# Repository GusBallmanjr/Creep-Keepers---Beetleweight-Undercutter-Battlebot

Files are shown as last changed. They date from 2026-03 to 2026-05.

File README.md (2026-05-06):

# 3 lb Undercutter BattleBot
## Crimson Robotics (Washington State University)

**Creep Keepers** - Gus Ballman[^1], Carson Roskelley[^2], Jayden Claytor[^3], Natalie Massarenti[^4]

---

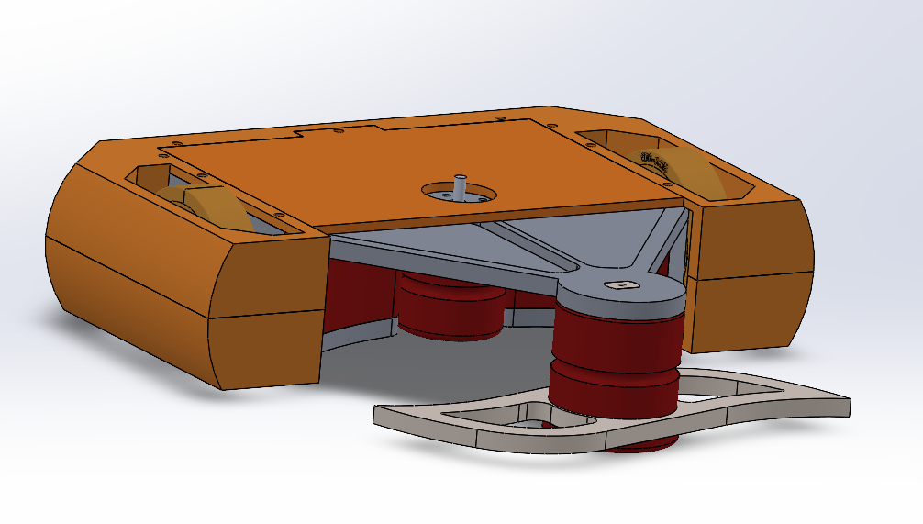
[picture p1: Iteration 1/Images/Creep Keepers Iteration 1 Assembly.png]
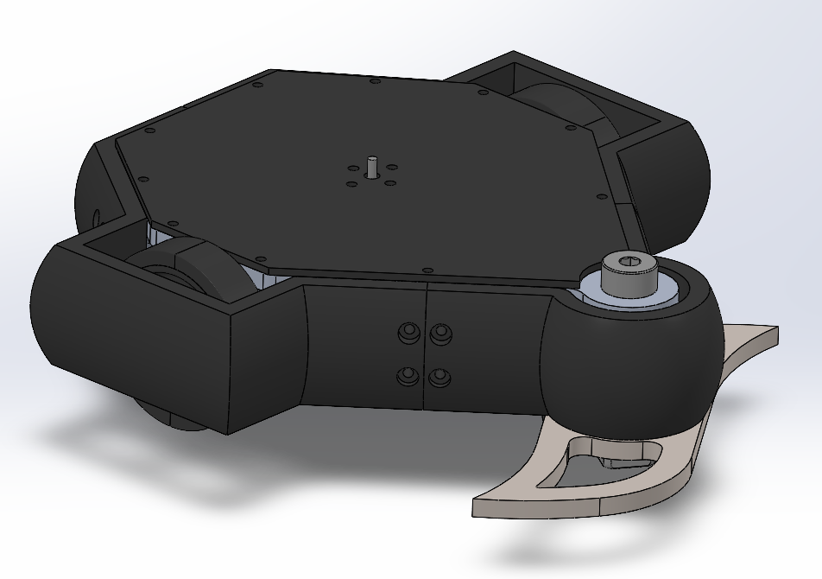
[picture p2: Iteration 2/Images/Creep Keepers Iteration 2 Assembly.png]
  <br>
&nbsp;&nbsp;&nbsp;&nbsp;&nbsp;&nbsp;&nbsp;&nbsp;&nbsp;&nbsp;&nbsp;&nbsp;&nbsp;&nbsp;&nbsp;&nbsp;&nbsp;&nbsp;&nbsp;&nbsp;&nbsp;&nbsp;&nbsp;&nbsp;&nbsp;&nbsp;&nbsp;&nbsp; *Iteration 1* &nbsp;&nbsp;&nbsp;&nbsp;&nbsp;&nbsp;&nbsp;&nbsp;&nbsp;&nbsp;&nbsp;&nbsp;&nbsp;&nbsp;&nbsp;&nbsp;&nbsp;&nbsp;&nbsp;&nbsp;&nbsp;&nbsp;&nbsp;&nbsp;&nbsp;&nbsp;&nbsp;&nbsp;&nbsp;&nbsp;&nbsp;&nbsp;&nbsp;&nbsp;&nbsp;&nbsp;&nbsp;&nbsp;&nbsp;&nbsp;&nbsp;&nbsp;&nbsp;&nbsp;&nbsp;&nbsp;&nbsp;&nbsp;&nbsp;&nbsp;&nbsp;&nbsp;&nbsp;&nbsp;&nbsp;&nbsp;&nbsp;&nbsp;&nbsp;&nbsp;&nbsp;&nbsp;&nbsp;&nbsp;&nbsp;&nbsp;&nbsp;&nbsp;&nbsp;&nbsp;&nbsp;&nbsp;&nbsp;&nbsp;&nbsp;&nbsp;&nbsp;&nbsp;&nbsp;&nbsp; *Iteration 2* &nbsp;&nbsp;&nbsp;&nbsp;

---

#### Iterations
+ [Prototype Files & Documentation](https://github.com/GusBallmanjr/Creep-Keepers---Beetleweight-Undercutter-Battlebot/blob/main/Prototype/Documentation/Prototype.md)
+ [Iteration 1 Files & Documentation](https://github.com/GusBallmanjr/Creep-Keepers---Beetleweight-Undercutter-Battlebot/blob/main/Iteration%201/Documentation/i1.md)
+ [Iteration 2 Files & Documentation](https://github.com/GusBallmanjr/Creep-Keepers---Beetleweight-Undercutter-Battlebot/blob/main/Iteration%202/Documentation/i2.md)

---

#### File Structure
```text
Creep Keepers Beetleweight Undercutter Battlebot
|
| --> / Prototype
|         | --> CAD
|         |      | --> Assemblies
|         |      | --> Parts
|         |
|         | --> Documentation
|         |      | --> prototype.md
|
| --> / Iteration 1
|         | --> CAD
|         |      | --> Assemblies
|         |      | --> Parts
|         |
|         | --> Documentation
|         |      | --> i1.md
|         |
|         | --> Images
|
| --> / Iteration 2
|         | --> CAD
|         |      | --> Assemblies
|         |      | --> Parts
|         |              | --> Armor
|         |              | --> Spinner Assembly
|         |              | --> Chassis
|         |
|         | --> Documentation
|         |      | --> i2.md
|         |
|         | --> Images
|         |
|         |--> Machining
|         |      | --> Gcode (Drilling)
|         |      | --> CNC Setup Sheets
|
```
[^1]: Worked on all iterations.
[^2]: Worked on all iterations.
[^3]: Worked on iteration 1.
[^4]: Worked on iteration 1.

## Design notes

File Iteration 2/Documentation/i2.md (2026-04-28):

# Creep Keepers — Beetleweight Undercutter  
## Iteration 2 (Spring 2026 → Completed April 2026)
## Nickname - "Chuckles"

+ Iteration 2 (Chuckles) was the second competitive version following the first iteration used at the fall 2025 Crimson Robotics Bot Brawl. Developed by **Gus Ballman, Carson Roskelley**. This build focused on refining the chassis (removing material), improving internal layout, and improved weapon stack.

---

## Iteration 2 Summary

+ **Competition Record:**
+ **Weigh‑In:**
+ **Completion Date:** April 24th, 2025  
+ **Armor Status:** 

| Subsystem | Material(s) | Mass |
|---|---|---|
| **Chassis** | 6061 Aluminum | _ lb |
| **Internal Walls** | TPU | _ lb  |
| **Spinner Assembly** | AR 500 Weapon Spinner, Alloy Steel bearings, TPU spacers and PLA pulleys | lb ( lb spinner ) |
| **Armor** | TPU | lb |

---

## Key Issues Identified
+ Overtensioning of spinner assembly belt
+ Too much friction stemming from bottom chassis support loop for spinner assembly.
+ Lack of space for electronics
+ Difficult to assemble

---

## Lessons Learned
+ Remove support loop for spinner assembly on bottom chassis
+ Need a more robust prototype phase (3d printing and testing model)
+ Need to be able to adjust for tolerances on belt tensioning

---

## Iteration 2 Assembly

*(Insert assembly photos or CAD renders here — e.g., `images/i2_assembly.png`)*
The assembly emphasized:
+ Structural support
+ Material efficency

---

## Iteration 2 Interior

*(Insert interior photos or CAD screenshots here — e.g., `images/i2_interior.png`)*

The interior layout emphasized:
+ Cleaner wiring paths     
+ Better separation between weapon and drive electronics

---

## File Structure

```text
/ Iteration 2
|
| --> CAD
|     | --> Assemblies
|     | --> Parts
|            | --> Armor
|            | --> Spinner Assembly
|            | --> Chassis
|
| --> Documentation
|     | --> i2.md
|
| --> Machining
|     | --> Gcode (Drilling)
|     | --> CNC Setup Sheets
```

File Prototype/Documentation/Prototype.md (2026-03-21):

# Creep Keepers — Beetleweight Undercutter (Fall 2025)
## Crimson Robotics (Washington State University)

A 3‑lb beetleweight undercutter combat robot developed in early Fall 2025 by  
**Gus Ballman, Carson Roskelley, Jayden Claytor, Natalie Massarenti**.

This prototype focused on a lightweight but rigid aluminum chassis, a TPU‑buffered weapon stack, and a hybrid PLA/TPU internal structure optimized for manufacturability and rapid iteration.

---

## Overview

| Subsystem | Material(s) | Mass |
|---|---|---|
| **Chassis** | 6061 Aluminum | 1.25 lb |
| **Side & Internal Walls** | PLA | ~0.18 lb |
| **Weapon Stack** | Alloy Steel blade & bearing, TPU spacers, TPU/PLA O‑ring holder | ~0.39 lb (0.37 lb blade) |
| **Top & Back Armor** | TPU (single printed piece) | .17 lb |

---

## Chassis

**Material:** 6061 Aluminum  
**Mass:** 1.25 lb  

The chassis serves as the primary structural frame, providing rigidity for the undercutter weapon system and protection for internal components. Aluminum 6061 was selected for its balance of machinability, strength, and weight.

---

## Side & Internal Wall Assembly

**Material:** PLA  
**Mass:** ~0.18 lb  

These printed walls form the internal compartmentalization for electronics and help constrain the weapon stack and drivetrain. PLA was chosen for ease of printing and dimensional stability during prototyping.

---

## Weapon Stack

A compact, high‑inertia undercutter assembly designed around a steel blade and TPU damping elements.

**Components:**
+ **Blade:** AR 500 Steel  
+ **Needle Bearing:** Alloy Steel  
+ **Bottom Spacer:** PLA 
+ **Top O‑Ring Holder:** PLA  
+ **Total Mass:** 2.57 lb  
  - **Blade Mass:** 0.36 lb  

The TPU spacers and O‑ring holder provide vibration damping and help maintain axial alignment during high‑speed operation.

---

## Internal Organization

The internal layout prioritizes:
+ Clean separation of electronics and weapon drive  
+ Shock‑isolated mounting points  
+ Straightforward wiring paths  
+ Rapid serviceability between matches 

---

## Top & Back Armor Plate

**Material:** TPU  
**Manufacturing:** Printed as a single piece  

The TPU armor provides flexible impact absorption and reduces the likelihood of brittle failure during weapon‑to‑weapon engagements.

---

## Project Timeline

+ **Development Period:** Early Fall 2025  
+ **Status:** Tested and redeveloped for competition. (See Iteration 1)

---

## Media & CAD

---

## File Structure

```text
/ Prototype
|
| --> CAD
|     | --> Assemblies
|     | --> Parts
|
| --> Documentation
|     | --> Prototype.md
```

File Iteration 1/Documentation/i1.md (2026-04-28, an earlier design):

# Creep Keepers — Beetleweight Undercutter  
## Iteration 1 (Fall 2025 → Completed November 2025)
## Nickname - "Eduardo"

+ Iteration 1 (Eduardo) was the first competitive version following the early‑fall prototype developed by **Gus Ballman, Carson Roskelley, Jayden Claytor, and Natalie Massarenti**. This build focused on refining the chassis, improving internal layout, and preparing the robot for its first full event. While the bot successfully entered competition, several structural and weight‑related issues limited overall performance.

---

## Iteration 1 Summary

+ **Competition Record:** 1–2  
+ **Weigh‑In:** 2.99 lb  (without armor)
+ **Completion Date:** November 2025  
+ **Armor Status:** Wheel‑side armor removed due to weight constraints  

| Subsystem | Material(s) | Mass |
|---|---|---|
| **Chassis** | 6061 Aluminum | 1.18 lb |
| **Internal Walls** | PLA | .2 lb (with 100% infill) |
| **Weapon Stack** | AR 500 Weapon Spinner & Alloy Steel bearings, PLA spacers and O‑ring holder | .62 lb ( .48 lb spinner ) |
| **Armor** | TPU | .8 lb |

---

## Key Issues Identified

Iteration 1 revealed several critical design flaws that directly impacted performance and reliability:

### **1. Incorrect Material Selection in CAD**
The CAD model used the wrong aluminum alloy (has since been changed), causing the predicted mass to be significantly lower than the real manufactured part.  
> “CAD model of chassis used an incorrect aluminum alloy causing mass issues”

### **2. Weight Overruns**
The robot exceeded the 3 lb limit until armor was removed.  
> “Armor had to be removed to meet the 3 lb weight limit”

### **3. Insufficient Structural Stiffness**
The frame lacked the rigidity required for an undercutter weapon system, reducing energy transfer and increasing vibration.  
> “Structural stiffness was insufficient for an undercutter weapon system”

### **4. Inefficient Material Usage**
Despite using more material than the prototype, the structure provided less support.  
> “Overall design used more material but provided less structural support”

---

## Lessons Learned

Iteration 1 provided several important takeaways that shaped future revisions:

+ **Material selection must balance strength, machinability, and density**  
+ **Weight budgeting must begin early in the design process**  
+ **Undercutters require a rigid frame to transfer weapon energy effectively**

---

## Iteration 1 Assembly

*(Insert assembly photos or CAD renders here — e.g., `images/i1_assembly.png`)*

This version introduced:
+ A refined chassis layout  
+ Updated internal component placement  
+ Revised weapon stack mounting and spinner  
+ Early attempts at wheel‑side armor (later removed for weight)

---

## Iteration 1 Interior

*(Insert interior photos or CAD screenshots here — e.g., `images/i1_interior.png`)*

The interior layout emphasized:
+ Cleaner wiring paths     
+ Better separation between weapon and drive electronics

---

## File Structure

```text
/ Iteration 1
|
| --> CAD
|     | --> Assemblies
|     | --> Parts
|
| --> Documentation
|     | --> i1.md
```

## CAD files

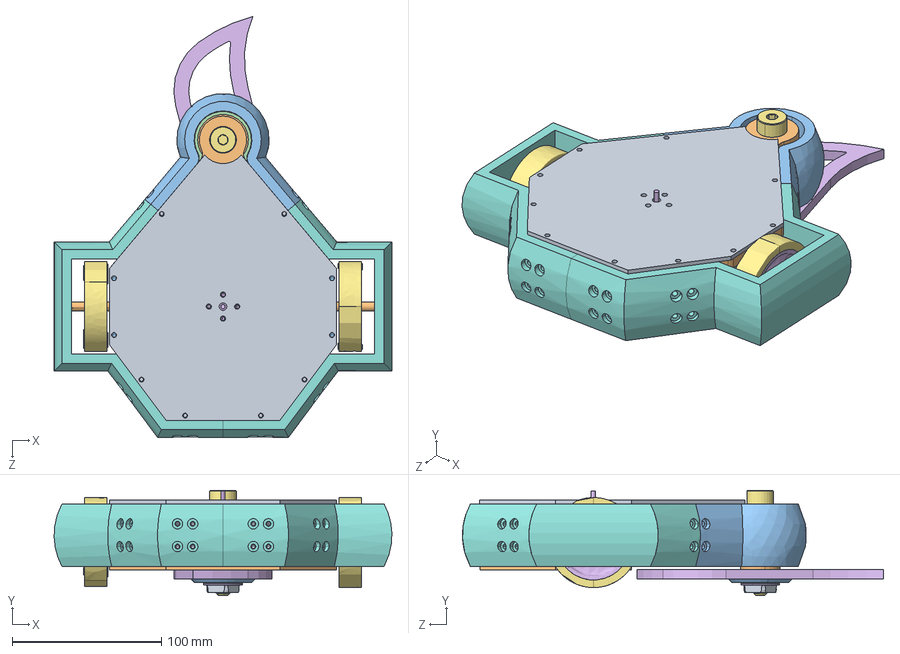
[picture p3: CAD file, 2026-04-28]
Iteration 2/CAD/Assemblies/Chuckles Assembly.STEP
226.4 x 70.4 x 282.1 mm
Wall Rod x 6
Chassis Top Plate
Chassis Side Wall x 2
Chassis Bottom Plate
Weapon Motor Pulley
Weapon
5905K53_Needle-Roller Bearing (1)_5905K53
Weapon Pulley
Clover
5909K12_Needle-Roller Thrust Bearing_5909K12 x 2
5909K72_1 mm Thick Washer for 12 mm Shaft Diameter Needle-Roller Thrust Bearing_5909K72 x 3
Spacer (Weapon Stack)
______________PGM24+TM2006Modified.STEP.STEP x 2
____-0__________PGM24+TM2006Modified.STEP.STEP x 2
3x7x3______________PGM24+TM2006Modified.STEP.STEP x 4
____-1_________-1_PGM24+TM2006Modified.STEP.STEP x 2
___________-1_PGM24+TM2006Modified.STEP.STEP x 2
____-2_________-1_PGM24+TM2006Modified.STEP.STEP x 2
____-3_________-1_PGM24+TM2006Modified.STEP.STEP x 28
C____6_Max V2 GB(2)_Max V2 GB.STEP x 2
GMP24______19.4_M0.4X46_Max V2 GB(2)_Max V2 GB.STEP x 2
GMP24_______Max V2 GB(2)_Max V2 GB.STEP x 2
_______Max V2 GB(2)_Max V2 GB.STEP x 2
___________Max V2 GB(2)_Max V2 GB.STEP x 2
____686RS_Max V2 GB(2)_Max V2 GB.STEP x 4
t60 hub_Vf x 2
T6-A1_Vf x 2
Armor Side Wall x 2
Top Armor
Bottom Armor
Front Armor
Tattu 4S Battery
Fingertech_Mini_Power_Switch_Vf
2826 EVO
92981A420_Alloy Steel Shoulder Screws_92981A420
97258A106_18-8 Stainless Steel Thin-Profile Square Nuts_97258A106

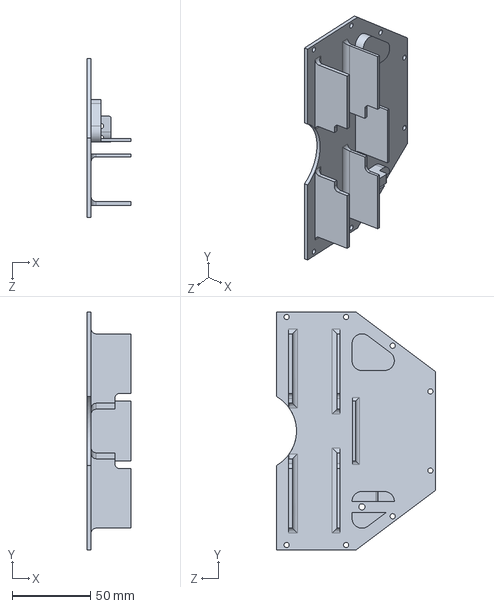
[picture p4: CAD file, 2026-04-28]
Iteration 2/CAD/Parts/Armor/Bottom Armor.STEP
27.9 x 152.4 x 101.6 mm

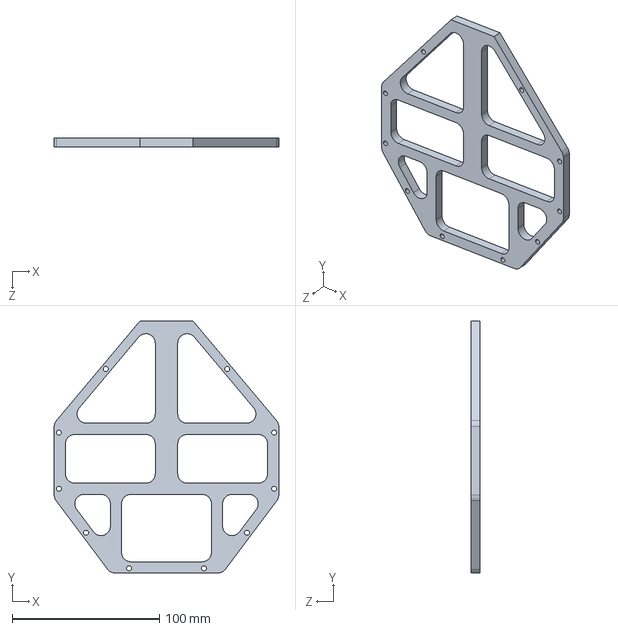
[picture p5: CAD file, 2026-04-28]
Iteration 2/CAD/Parts/Chassis/Chassis Bottom Plate.STEP
152.4 x 171.0 x 6.35 mm

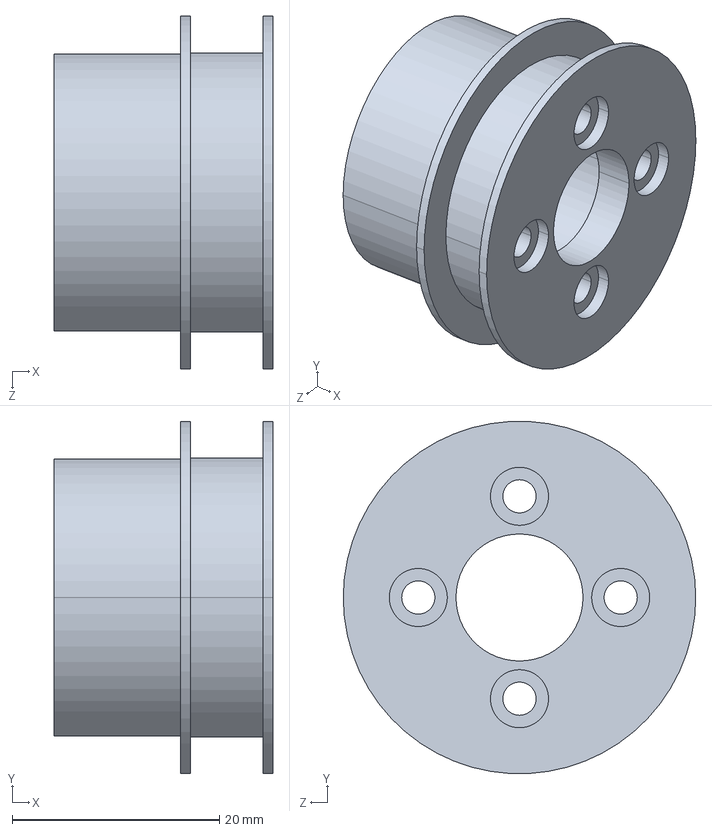
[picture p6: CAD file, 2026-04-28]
Iteration 2/CAD/Parts/Spinner Assembly/Spinner Pulley.STEP
21.1 x 34.0 x 34.0 mm

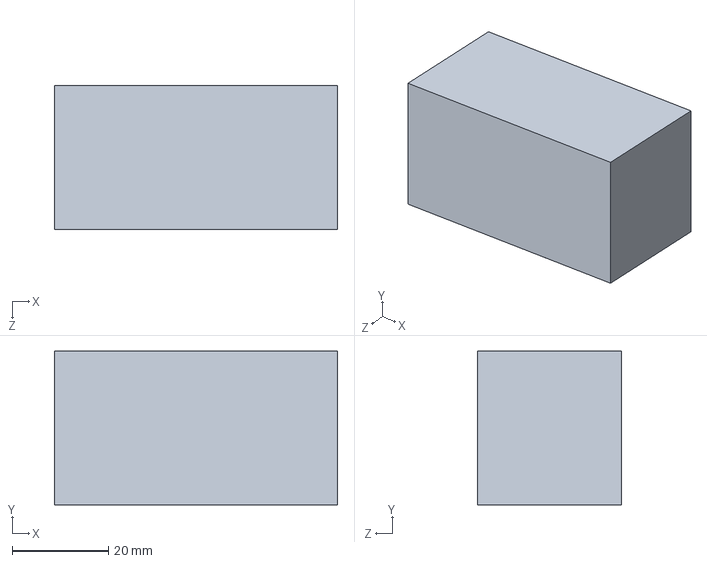
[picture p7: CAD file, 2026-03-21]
Prototype/CAD/Parts/Tattu 4S Battery.STEP
58.9 x 32.0 x 30.0 mm

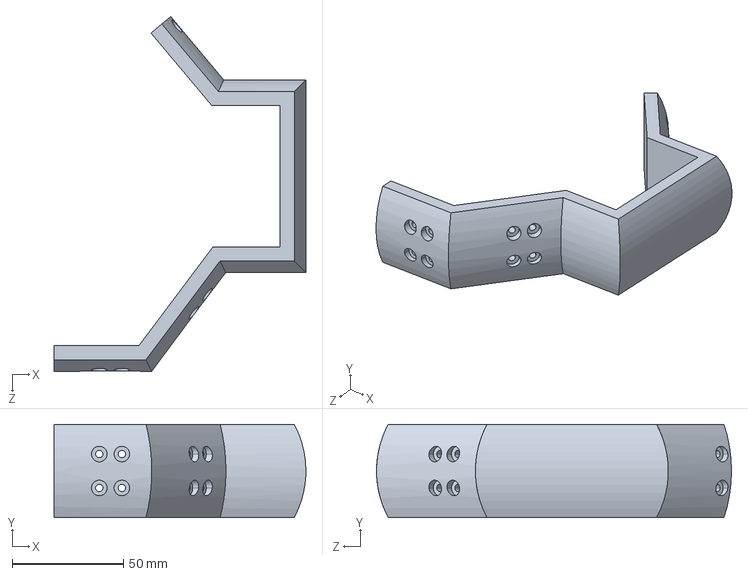
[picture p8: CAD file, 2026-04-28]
Iteration 2/CAD/Parts/Armor/Armor Side Wall.STEP
113.2 x 41.9 x 159.6 mm

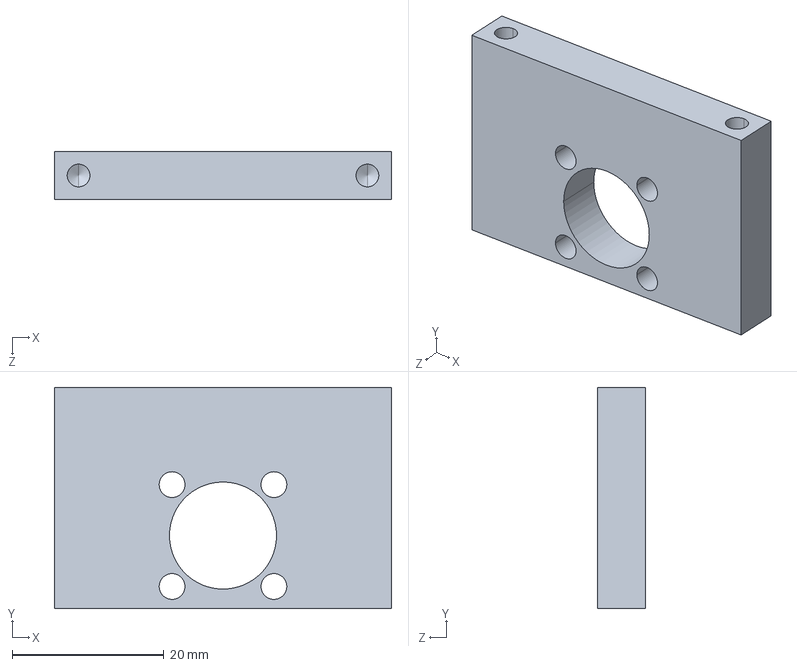
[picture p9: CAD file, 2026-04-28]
Iteration 2/CAD/Parts/Chassis/Chassis Side Wall.STEP
44.4 x 29.2 x 6.35 mm

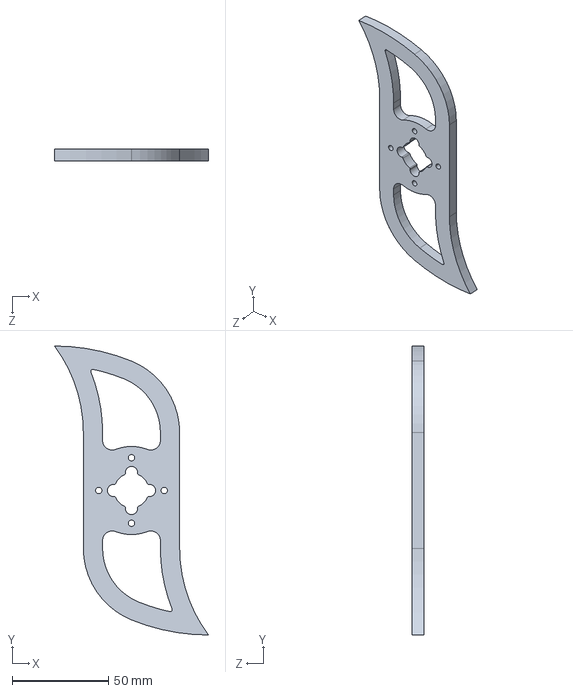
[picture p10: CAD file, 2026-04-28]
Iteration 2/CAD/Parts/Spinner Assembly/Spinner.STEP
80.0 x 150.0 x 6.35 mm

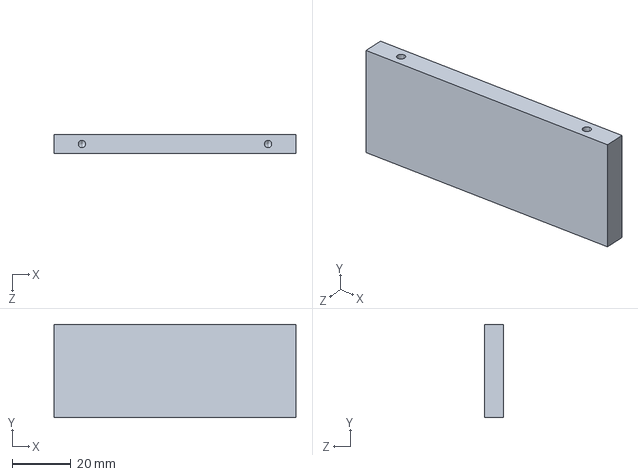
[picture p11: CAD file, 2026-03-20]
Prototype/CAD/Parts/Front Wall.STEP
82.5 x 31.8 x 6.35 mm

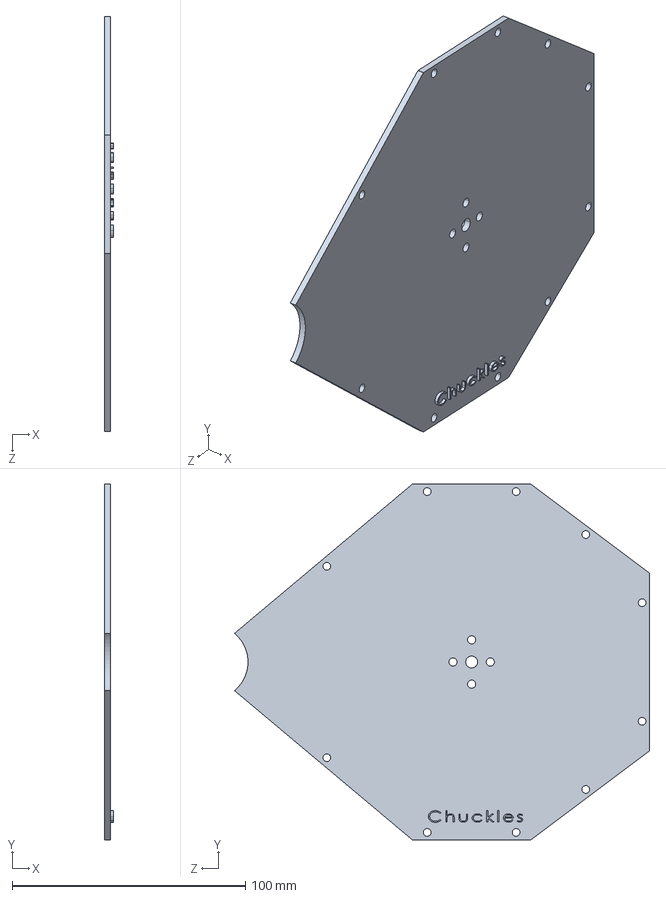
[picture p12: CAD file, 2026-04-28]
Iteration 2/CAD/Parts/Armor/Top Armor.STEP
3.81 x 152.4 x 177.8 mm

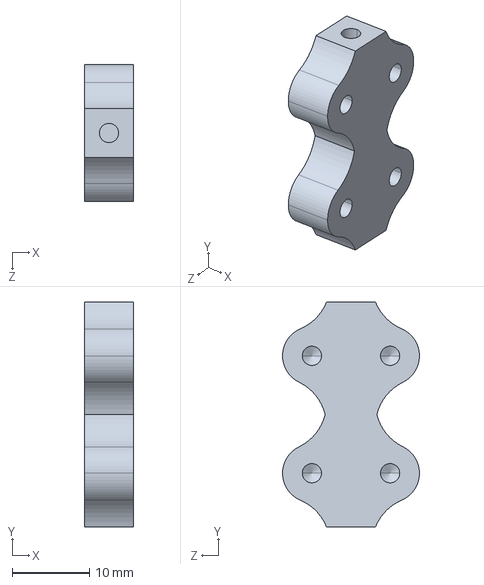
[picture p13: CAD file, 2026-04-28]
Iteration 2/CAD/Parts/Chassis/Wall Rod.STEP
6.35 x 29.2 x 17.8 mm

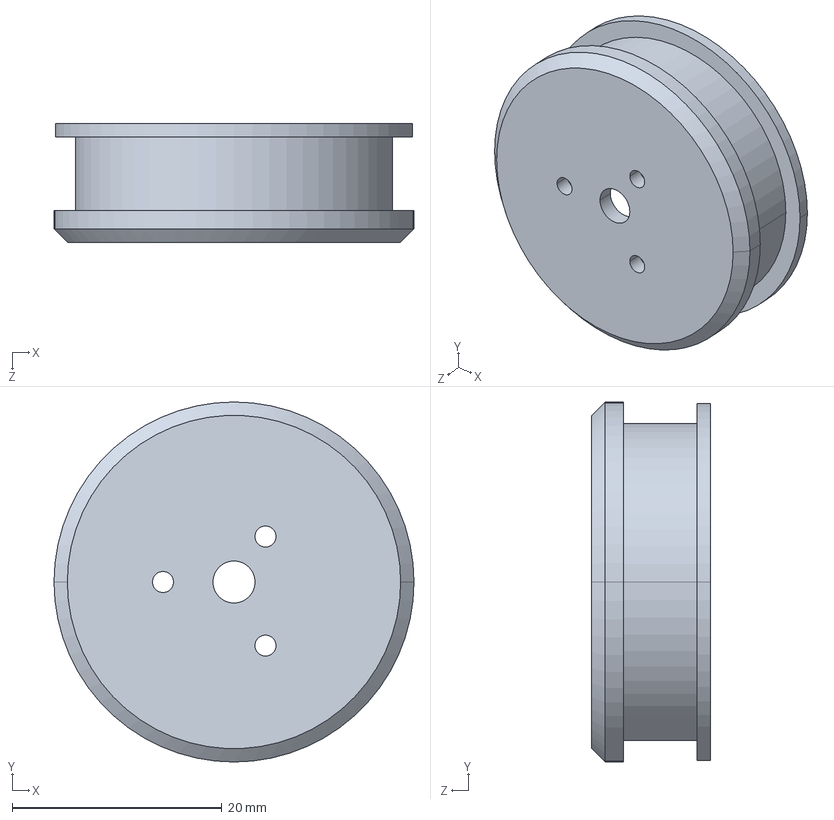
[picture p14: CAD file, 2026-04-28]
Iteration 2/CAD/Parts/Spinner Assembly/Spinner Motor Pulley.STEP
34.3 x 34.3 x 11.3 mm

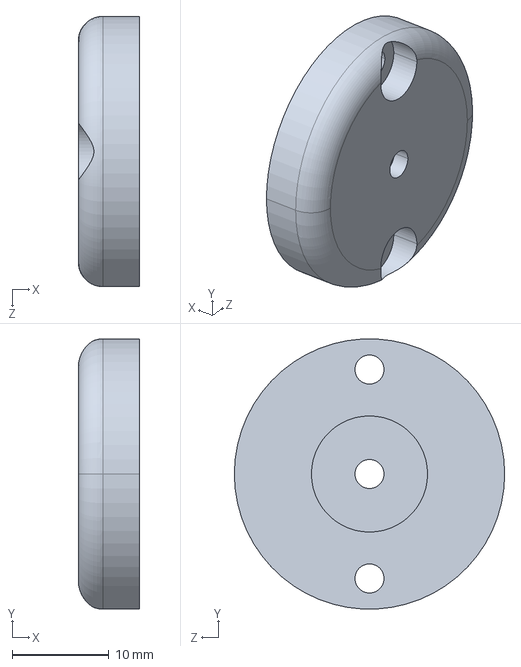
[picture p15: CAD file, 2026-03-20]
Prototype/CAD/Parts/Bottom Weapon Stack Spacer.STEP
6.35 x 27.9 x 27.9 mm

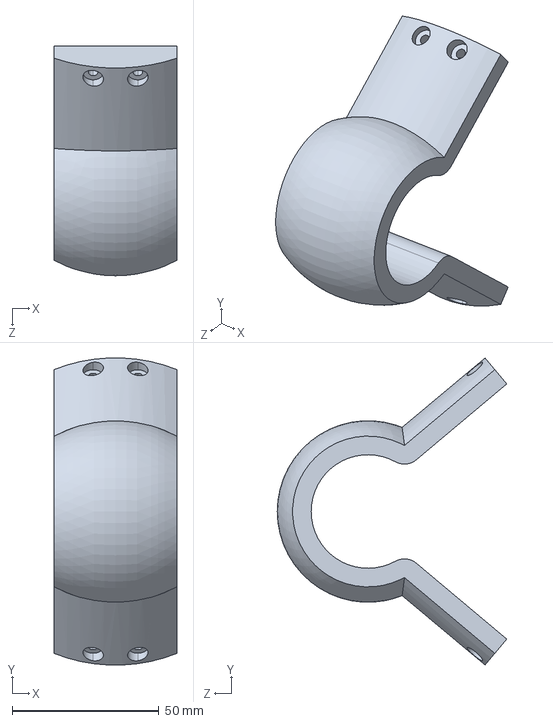
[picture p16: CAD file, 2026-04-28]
Iteration 2/CAD/Parts/Armor/Front Armor.STEP
41.9 x 104.7 x 78.3 mm

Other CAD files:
Prototype/CAD/Assemblies/Weapon Stack Version 2.SLDASM
Prototype/CAD/Assemblies/Prototype.SLDASM
Prototype/CAD/Assemblies/Walls SubAssembly.SLDASM
Iteration 2/CAD/Parts/Chassis/Chassis Top Plate.STEP
Iteration 1/CAD/Assemblies/Iteration 1.STEP
Iteration 1/CAD/Assemblies/Weapon Stack_Vf.SLDASM
Iteration 1/CAD/Assemblies/roller + washer bearing_Vf.SLDASM
Iteration 1/CAD/Parts/2836 EVO_Vf.STEP
Iteration 1/CAD/Parts/5905K53_Needle-Roller Bearing_Vf.STEP
Iteration 1/CAD/Parts/5909K12_Needle-Roller Thrust Bearing_Vf.STEP
Iteration 1/CAD/Parts/5909K72_1 mm Thick Washer for 12 mm Shaft Diameter Needle-Roller Thrust Bearing_Vf.STEP
Iteration 1/CAD/Parts/Back Wall_Vf.STEP
Iteration 1/CAD/Parts/Bottom Plate_Vf.STEP
Iteration 1/CAD/Parts/Fingertech_Mini_Power_Switch_Vf.STEP
Iteration 1/CAD/Parts/Internal Walls_Vf.STEP
Iteration 1/CAD/Parts/MaxV2_Vf.STEP
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

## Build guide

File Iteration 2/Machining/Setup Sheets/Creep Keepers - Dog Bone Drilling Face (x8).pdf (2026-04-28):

# Setup Sheet for Program 1001

Job Description: Side M3 Tap Document Path: Wall Rod v5

## Setup

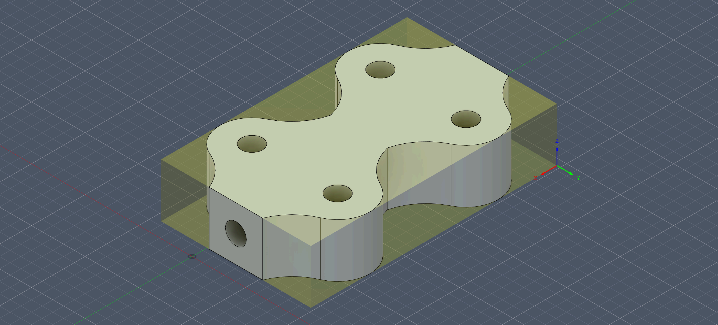
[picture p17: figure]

WCS: #1

Stock:
DX: 1.15in
DY: 0.7in
DZ: 0.25in

Part:
DX: 1.15in
DY: 0.7in
DZ: 0.25in

Stock Lower in WCS #1:
X: 0in
Y: -0.7in
Z: 0in

Stock Upper in WCS #1:
X: 1.15in
Y: 0in
Z: 0.25in

## Total

Number Of Operations: 1
Number Of Tools: 1
Tools: T103
Maximum Z: 0.85in
Minimum Z: 0.1in
Maximum Feedrate: 9in/min
Maximum Spindle Speed: 7500rpm Cutting Distance: 1.398in
Rapid Distance: 3.598in
Estimated Cycle Time: 24s

## Tools

T103 D103 L103
Type: drill
Diameter: 0.098in
Tip Angle: 118°
Length: 5.118in
Flutes: 2
Description: M3 Tap Drill

Minimum Z: 0.1in
Maximum Feedrate: 9in/min
Maximum Spindle Speed: 7500rpm Cutting Distance: 1.398in
Rapid Distance: 3.598in
Estimated Cycle Time: 9s

## Operations

4/27/26, 9:07 AM | Setup Sheet for Program 1001
file:///C:/Users/Owner/OneDrive - Washington State University (email.wsu.edu)/Creep Keepers Machining Setup Sheets Spring 2026/Wall Rod v5.html | 1/2

Operation 1/1
Description: Drill1
Strategy: Drilling
WCS: #1
Tolerance: 0in
Stock to Leave: 0in

Maximum Z: 0.85in
Minimum Z: 0.1in
Maximum Spindle Speed: 7500rpm Maximum Feedrate: 9in/min
Cutting Distance: 1.398in
Rapid Distance: 3.598in
Estimated Cycle Time: 9s
Coolant: Flood

T103 D103 L103
Type: drill
Diameter: 0.098in
Tip Angle: 118°
Length: 5.118in
Flutes: 2
Description: M3 Tap Drill

Generated by Fusion CAM 2702.1.47 (http://cam.autodesk.com/) 4/27/2026 9:06:03 AM

4/27/26, 9:07 AM | Setup Sheet for Program 1001
file:///C:/Users/Owner/OneDrive - Washington State University (email.wsu.edu)/Creep Keepers Machining Setup Sheets Spring 2026/Wall Rod v5.html | 2/2

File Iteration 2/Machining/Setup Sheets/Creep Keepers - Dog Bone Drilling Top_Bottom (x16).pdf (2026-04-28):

# Setup Sheet for Program 1001

Job Description: Top/Bottom M3 Tap Document Path: Wall Rod v5

## Setup

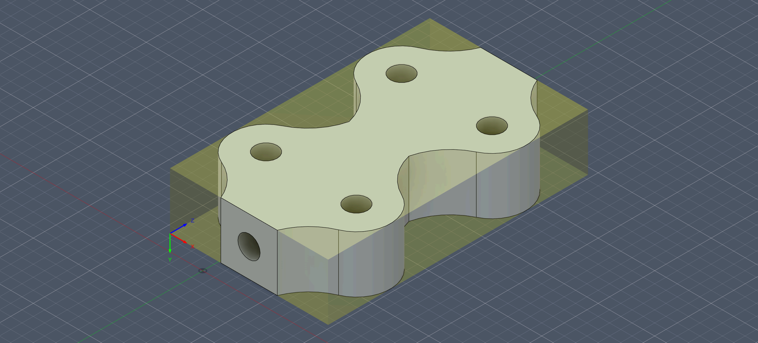
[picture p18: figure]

WCS: #1

Stock:
DX: 0.7in
DY: 0.25in
DZ: 1.15in

Part:
DX: 0.7in
DY: 0.25in
DZ: 1.15in

Stock Lower in WCS #1:
X: 0in
Y: -0.25in
Z: 0in

Stock Upper in WCS #1:
X: 0.7in
Y: 0in
Z: 1.15in

## Total

Number Of Operations: 1
Number Of Tools: 1
Tools: T103
Maximum Z: 1.75in
Minimum Z: 0.995in
Maximum Feedrate: 9in/min
Maximum Spindle Speed: 7500rpm Cutting Distance: 0.355in
Rapid Distance: 1.155in
Estimated Cycle Time: 17s

## Tools

T103 D103 L103
Type: drill
Diameter: 0.098in
Tip Angle: 118°
Length: 5.118in
Flutes: 2
Description: M3 Tap Drill

Minimum Z: 0.995in
Maximum Feedrate: 9in/min
Maximum Spindle Speed: 7500rpm Cutting Distance: 0.355in
Rapid Distance: 1.155in
Estimated Cycle Time: 2s

## Operations

4/27/26, 9:06 AM | Setup Sheet for Program 1001
file:///C:/Users/Owner/OneDrive - Washington State University (email.wsu.edu)/Creep Keepers Machining Setup Sheets Spring 2026/Wall Rod v5.html | 1/2

Operation 1/1
Description: Drill3
Strategy: Drilling
WCS: #1
Tolerance: 0in
Stock to Leave: 0in

Maximum Z: 1.75in
Minimum Z: 0.995in
Maximum Spindle Speed: 7500rpm Maximum Feedrate: 9in/min
Cutting Distance: 0.355in
Rapid Distance: 1.155in
Estimated Cycle Time: 2s
Coolant: Flood

T103 D103 L103
Type: drill
Diameter: 0.098in
Tip Angle: 118°
Length: 5.118in
Flutes: 2
Description: M3 Tap Drill

Generated by Fusion CAM 2702.1.47 (http://cam.autodesk.com/) 4/27/2026 9:06:16 AM

4/27/26, 9:06 AM | Setup Sheet for Program 1001
file:///C:/Users/Owner/OneDrive - Washington State University (email.wsu.edu)/Creep Keepers Machining Setup Sheets Spring 2026/Wall Rod v5.html | 2/2

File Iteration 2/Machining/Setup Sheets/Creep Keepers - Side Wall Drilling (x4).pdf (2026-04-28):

# Setup Sheet for Program 1001

## Job Description: Side Wall Drilling Document Path: Chassis Side Wall v5

## Setup

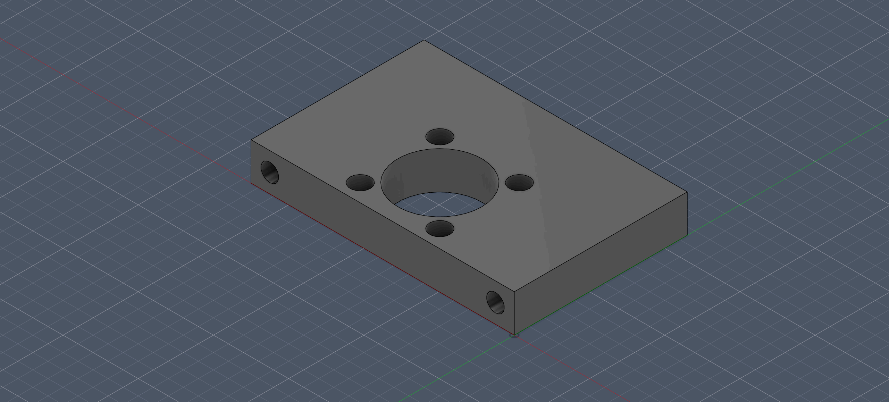
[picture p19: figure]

WCS: #1

Stock:
DX: 1.75in
DY: 0.25in
DZ: 1.15in

Part:
DX: 1.75in
DY: 0.25in
DZ: 1.15in

Stock Lower in WCS #1:
X: 0in
Y: -0.25in
Z: 0in

Stock Upper in WCS #1:
X: 1.75in
Y: 0in
Z: 1.15in

## Total

Number Of Operations: 1
Number Of Tools: 1
Tools: T103
Maximum Z: 1.75in
Minimum Z: 0.65in
Maximum Feedrate: 9in/min
Maximum Spindle Speed: 7500rpm Cutting Distance: 1.741in
Rapid Distance: 8.266in
Estimated Cycle Time: 27s

## Tools

T103 D103 L103
Type: drill
Diameter: 0.098in
Tip Angle: 118°
Length: 5.118in
Flutes: 2
Description: M3 Tap Drill

Minimum Z: 0.65in
Maximum Feedrate: 9in/min
Maximum Spindle Speed: 7500rpm Cutting Distance: 1.741in
Rapid Distance: 8.266in
Estimated Cycle Time: 12s

## Operations

4/27/26, 9:04 AM | Setup Sheet for Program 1001
file:///C:/Users/Owner/OneDrive - Washington State University (email.wsu.edu)/Creep Keepers Machining Setup Sheets Spring 2026/Chassis Side Wal… | 1/2

Operation 1/1
Description: Drill1
Strategy: Drilling
WCS: #1
Tolerance: 0in
Stock to Leave: 0in

Maximum Z: 1.75in
Minimum Z: 0.65in
Maximum Spindle Speed: 7500rpm Maximum Feedrate: 9in/min
Cutting Distance: 1.741in
Rapid Distance: 8.266in
Estimated Cycle Time: 12s
Coolant: Flood

T103 D103 L103
Type: drill
Diameter: 0.098in
Tip Angle: 118°
Length: 5.118in
Flutes: 2
Description: M3 Tap Drill

Generated by Fusion CAM 2702.1.47 (http://cam.autodesk.com/) 4/27/2026 9:04:40 AM

4/27/26, 9:04 AM | Setup Sheet for Program 1001
file:///C:/Users/Owner/OneDrive - Washington State University (email.wsu.edu)/Creep Keepers Machining Setup Sheets Spring 2026/Chassis Side Wal… | 2/2

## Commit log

2026-03-20 Update and rename Prototype.md to IterationOne.md
2026-03-20 Rename Version 1/CAD/Assemblies/V1.md to Iteration 2/CADAssemblies/V1.md
2026-03-20 Rename Iteration 2/CADAssemblies/V1.md to Iteration 2/CAD/Assemblies/V1.md
2026-03-21 Rename 2.375 T40 Wheel.STEP to 2.375 T40 Wheel.STEP
    [2.375 T40 Wheel.STEP]
2026-03-21 Rename Armor Back plate.STEP to Armor Back plate.STEP
    [Armor Back plate.STEP]
2026-03-21 Rename Bottom Chassis Plate.STEP to Bottom Chassis Plate.STEP
    [Bottom Chassis Plate.STEP]
2026-03-21 Rename Bottom Weapon Stack Spacer.STEP to Bottom Weapon Stack Spacer.STEP
    [Bottom Weapon Stack Spacer.STEP]
2026-03-21 Rename Chassis Back Wall Design 4.STEP to Chassis Back Wall Design 4.STEP
    [Chassis Back Wall Design 4.STEP]
2026-03-21 Rename Front Wall.STEP to Front Wall.STEP
    [Front Wall.STEP]
2026-03-21 Rename Internal Walls.STEP to Internal Walls.STEP
    [Internal Walls.STEP]
2026-03-21 Rename Motor Spacer.STEP to Motor Spacer.STEP
    [Motor Spacer.STEP]
2026-03-21 Rename O Ring Holder for motor.STEP to O Ring Holder for motor.STEP
    [O Ring Holder for motor.STEP]
2026-03-21 Rename O_ring holder base for Blade.STEP to O_ring holder base for Blade.STEP
    [O_ring holder base for Blade.STEP]
2026-03-21 Update and rename Tattu 4S Battery (1).STEP to Tattu 4S Battery.STEP
    [Tattu 4S Battery.STEP]
2026-03-21 Rename Top Chassis Plate.STEP to Top Chassis Plate.STEP
    [Top Chassis Plate.STEP]
2026-03-21 Rename Weapon Shaft.STEP to Weapon Shaft.STEP
    [Weapon Shaft.STEP]
2026-03-21 Rename Weapon Spinner.STEP to Weapon Spinner.STEP
    [Weapon Spinner.STEP]
2026-03-21 Rename Wheel Nut chamber.STEP to Wheel Nut chamber.STEP
    [Wheel Nut chamber.STEP]
2026-03-21 Rename Iteration 1.SLDASM to Iteration 1.SLDASM
    [Iteration 1.SLDASM]
2026-03-21 Update and rename q to Prototype.md
2026-04-28 Rename Spacer (Weapon Stack).STEP to Spacer.STEP
    [Spacer.STEP]
2026-04-28 Rename Weapon Pulley.STEP to Spinner Pulley.STEP
    [Spinner Pulley.STEP]
2026-04-28 Update Spinner Pulley.STEP
    [Spinner Pulley.STEP]
2026-04-28 Update and rename Weapon.STEP to Spinner.STEP
    [Spinner.STEP]
